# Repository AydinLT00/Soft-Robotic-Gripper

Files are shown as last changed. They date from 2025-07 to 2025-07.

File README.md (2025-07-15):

# Soft-Robotic-Gripper
# Bio-Inspired Soft Robotic Gripper with Arduino Control





This repository documents the design, fabrication, and testing of a 3-fingered, bio-inspired soft robotic gripper. The project leverages the intrinsic compliance of soft materials and an underactuated, tendon-driven mechanism to achieve adaptable and effective grasping of various objects. The entire system is controlled by a single servo motor managed by an Arduino Uno, demonstrating a low-cost, effective solution for robotic manipulation.

This work is inspired by the principles outlined in the paper *"A Bioinspired Soft Robotic Gripper for Adaptable and Effective Grasping"* (Manti et al., 2015).

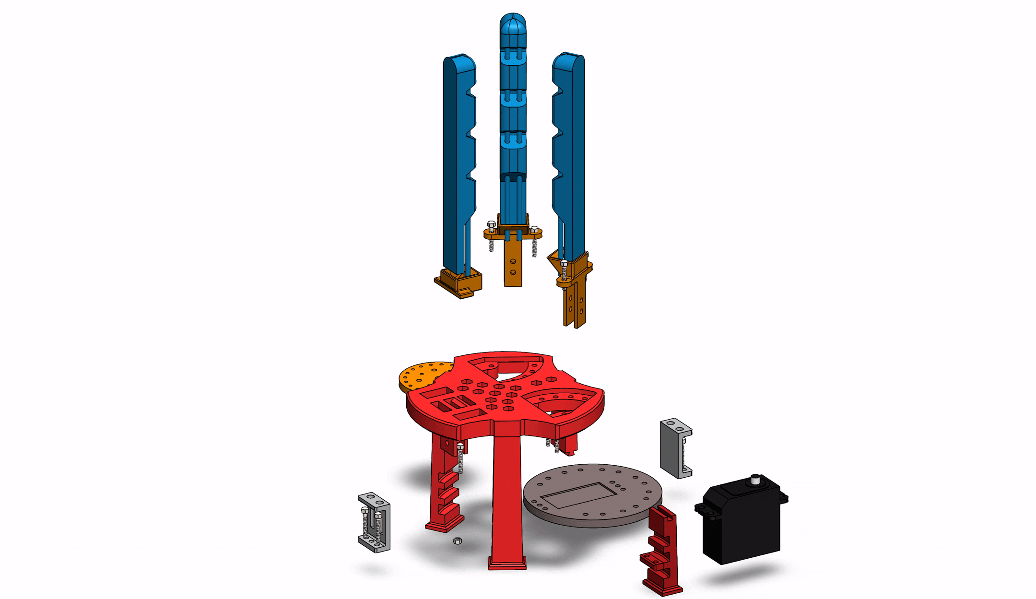
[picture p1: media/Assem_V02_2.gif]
CAD Render of the Gripper

*<p align="center">Final SolidWorks assembly of the soft gripper.</p>*

---

## 🚀 Showcase & Demos

The gripper successfully demonstrates versatile grasping capabilities, from delicate and irregular objects to lifting a significant payload.

### Live Grasping Demonstration
<!-- IMPORTANT: Create a GIF of your gripper in action and replace the URL below -->


*<p align="center">The gripper performing various pick-and-place tasks.</p>*

### Object Handling Capabilities
The gripper can handle a wide variety of shapes and sizes, thanks to its adaptive design.

| Gripping a Pack of Cookies | Holding a Screwdriver Set |
| :---: | :---: |
|  |  |

---

## 🔧 How It Works: Design & Principles

The gripper's effectiveness comes from a combination of four key design pillars.

### 1. Bio-Inspired Finger Design
The fingers are inspired by the biological structure of the human hand but are monolithically cast from soft silicone.
-   **Morphology:** Each finger has 4 phalanges created by 60° triangular cuts, promoting a larger contact area and natural bending.
-   **Materials:** We used a combination of silicones to balance flexibility and structural integrity:
    -   **Ecoflex™ 00-35:** A very soft silicone used for the ventral (gripping) side to maximize compliance and adapt to object shapes.
    -   **Smooth-Sil™ 950:** A stiffer silicone used for the dorsal side to provide restoring force and stability.
-   **Socket Integration:** The base of each finger is designed with a socket that interfaces with the 3D printed base, improving the flexion/extension mechanics.

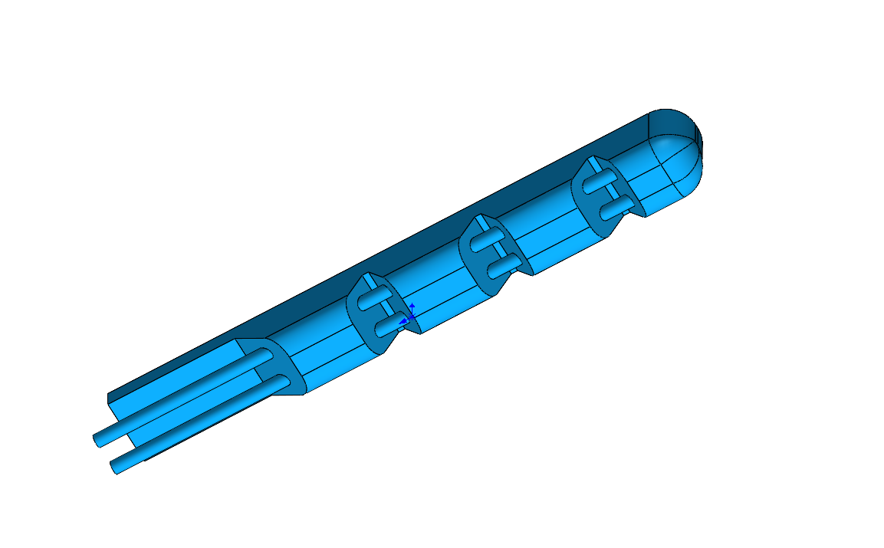
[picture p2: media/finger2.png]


### 2. Underactuated Tendon Mechanism
Simplicity and adaptability are achieved through an underactuated system.
-   **Single Actuator:** The entire 3-finger gripper is driven by a single high-torque servo motor.
-   **Differential Drive:** Multiple tendon (cable) is routed through all three fingers in a U-shape pattern. When the servo pulls the cable, it distributes the force among the fingers. If one finger is blocked, the others continue to close, allowing the gripper to passively conform to an object's shape.

### 3. 3D Printed Base
The palm of the gripper is a rigid base designed in SolidWorks and 3D printed.
-   **Function:** It serves as the mounting point for the fingers and integrates the servo motor.
-   **Features:** Includes tight-fit slots for the fingers to prevent wiggling and multiple mounting options for the servo plate.

| CAD Model | 3D Printed |
| :---: | :---: |
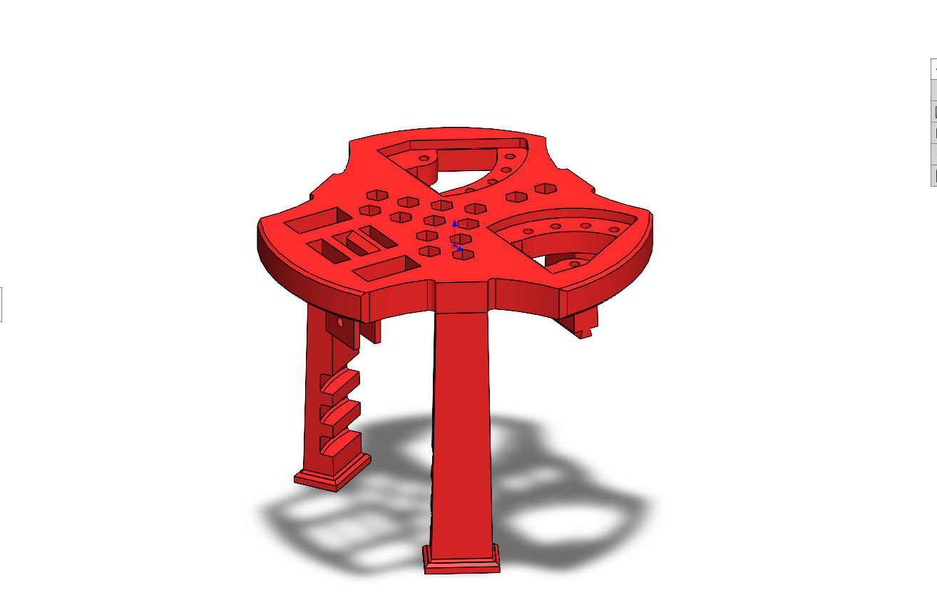
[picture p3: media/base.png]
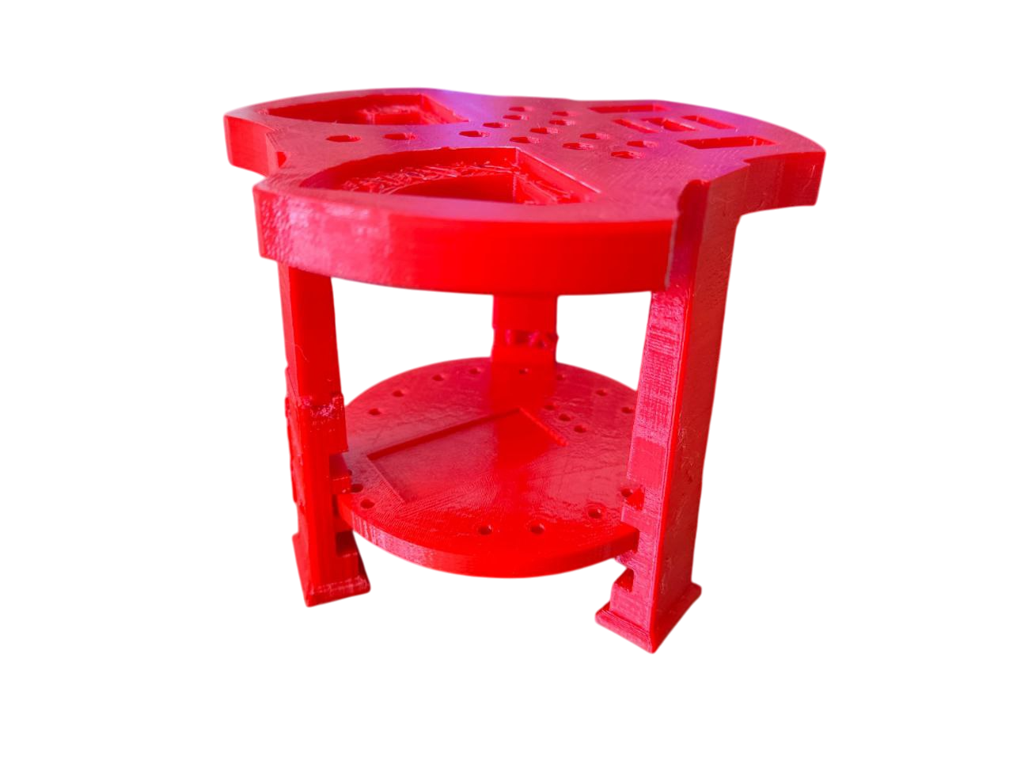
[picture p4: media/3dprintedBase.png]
|  |  |

### 4. Control System
The control is intentionally simple and low-cost.
-   **Hardware:** An **Arduino Uno** controls the position of the **servo motor**. The system is powered by a breadboard-based circuit.
-   **Software:** A simple script written in the **Arduino IDE** maps a desired grip state (open/closed) to a servo motor angle.

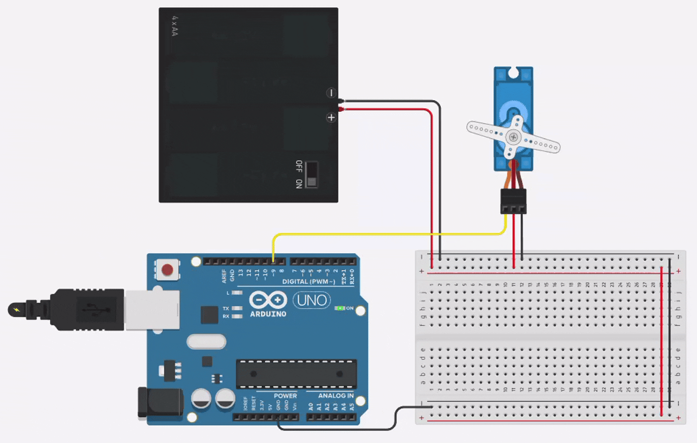
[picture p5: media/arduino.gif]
Control Circuit Diagram

*<p align="center">Circuit diagram for the servo motor control.</p>*

---

## 🛠️ Fabrication & Assembly

The fabrication process follows four main steps:
1.  **Design & Modeling:** The finger molds and base components were designed in **SolidWorks**.
2.  **3D Printing:** The molds and base were 3D printed using FDM technology with a 15% infill.
3.  **Casting:** The fingers were cast using the two-part silicone materials. Tubes were temporarily inserted into the molds to create pathways for the tendon cable.
4.  **Assembly & Wiring:** The cast fingers were mounted to the base, the servo was installed, and the tendon cable was routed and secured. Finally, the electronics were wired according to the circuit diagram.

---

## 📈 Performance & Results

-   **Payload Capacity:** The gripper successfully lifted a vertical payload of up to **1 Kg**.
-   **Grasping Versatility:** Demonstrated ability to handle delicate objects (like fruit) without damage and conform to irregular shapes.
-   **Limitations:** The gripper shows reduced stability on very smooth or wet surfaces (e.g., glass cups), where slipping can occur.

| PROS | CONS |
| :--- | :--- |
| ✅ **Adaptive Morphology:** Increased contact area and ability to handle delicate items. | ❌ **Limited Grip on Smooth Surfaces:** Prone to slipping on glass or wet objects. |
| ✅ **High Payload-to-Weight Ratio:** Lifts up to 1 Kg while being lightweight. | ❌ **Cleaning Challenges:** The soft Ecoflex material can be difficult to clean. |
| ✅ **Adjustable Configuration:** Finger orientation and tip distance can be manually set. | ❌ **Manual Configuration:** Setup requires manual adjustment. |
| ✅ **Fast & Low-Cost Fabrication:** Minimal printing hours and inexpensive materials. | ❌ **Friction in Cables:** Requires low-friction pathways for smooth actuation. |

---

## 💡 Future Work & Improvements

Based on the project's outcomes, several improvements could be implemented:
-   **Tension Adjustment Mechanism:** A mechanism to finely tune the tension of the tendon cables for each finger.
-   **High-Friction Cables/Pads:** Incorporating materials with a higher coefficient of friction to improve grip on smooth surfaces.
-   **Locking Mechanism:** A mechanical lock to hold the gripper in a specific configuration or grasp state without continuous servo power.

---

## ⚙️ How to Build Your Own

### Hardware Components
-   Arduino Uno
-   High-Torque Servo Motor (e.g., JX PDI-6221MG)
-   Ecoflex™ 00-35 & Smooth-Sil™ 950 Silicone
-   3D Printer and Filament (e.g., PLA)
-   Tendon Cable (e.g., high-strength fishing line)
-   Breadboard, Jumper Wires, and a 6V Power Supply

### Software & Files
-   **SolidWorks:** For viewing/editing the CAD files.
-   **Arduino IDE:** For programming the microcontroller.
-   **CAD Files:** All `.SLDPRT` and `.SLDASM` files are located in the `/SolidWorks` directory. Exported `.STL` files for printing are in the `/STL_for_Printing` directory.
-   **Arduino Code:** The control code is available in `/Arduino_Code/gripper_control.ino`.

### Assembly Instructions
1.  **3D Print** all components from the `/STL_for_Printing` directory.
2.  **Cast** the three soft fingers using the printed molds, following the two-part silicone mixing instructions.
3.  **Assemble** the base and mount the servo motor.
4.  **Mount** the fingers onto the base.
5.  **Route** the tendon cable through the fingers and attach it to the servo horn.
6.  **Wire** the electronics according to the circuit diagram above.
7.  **Upload** the `gripper_control.ino` sketch to your Arduino Uno.

---

## License

This project is shared for educational purposes. All rights are reserved. Please see the `LICENSE` file for more details.

## 🙏 Acknowledgments

This project was inspired by the work of Manti, Hassan, Passetti et al. and was completed as part of our studies at **Politecnico di Milano**. Special thanks to our professors and team members.

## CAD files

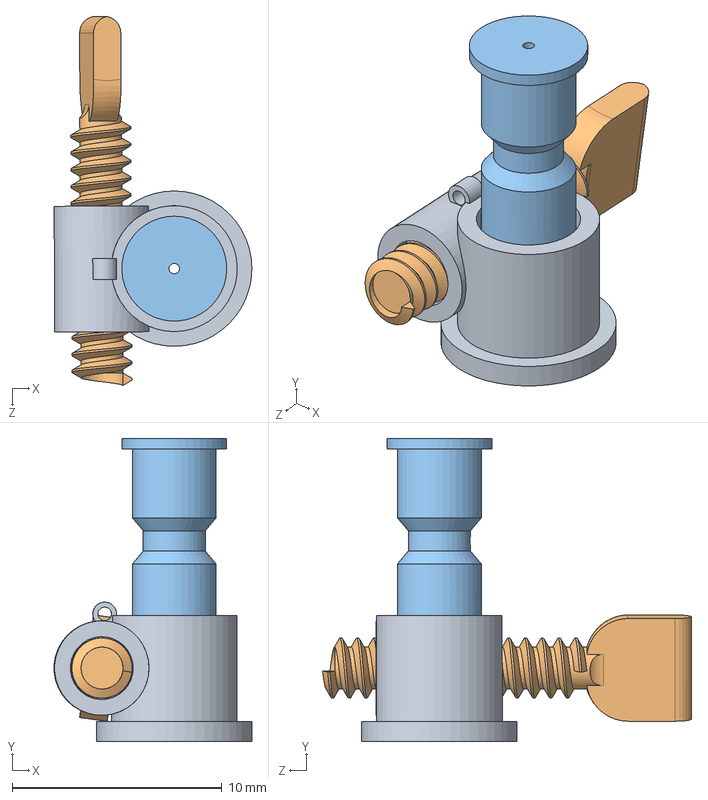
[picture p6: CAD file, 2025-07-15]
Solidworks/WormGearAssembly.SLDASM
9.43 x 14.4 x 17.6 mm
WormGearVertical
WormGearHorizontal
wormConnect

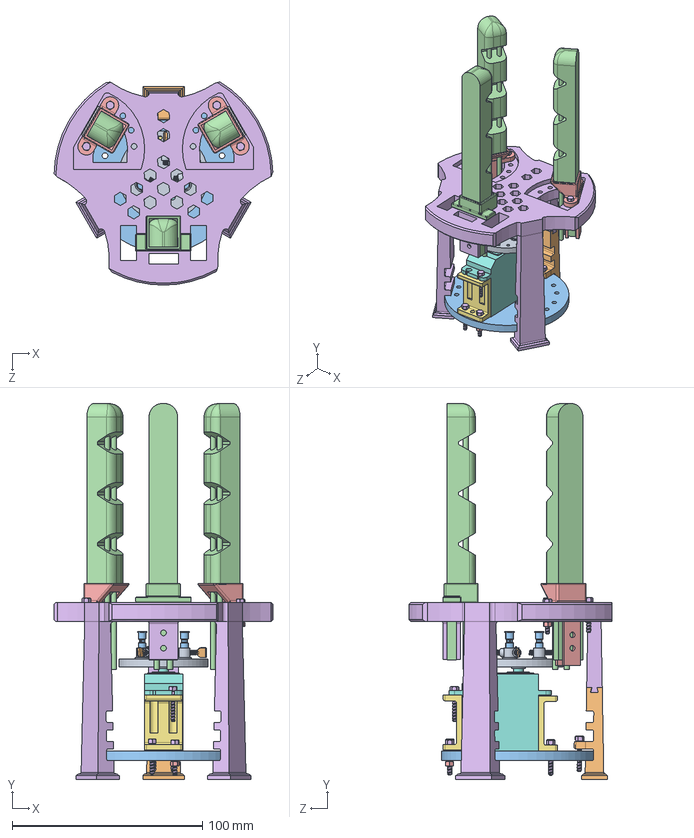
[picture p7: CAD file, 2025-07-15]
Solidworks/Assem_V02_WormGearCheck.SLDASM
115.0 x 197.5 x 106.8 mm
Base_main_attach_V02_WormGearCheck
rotate_binder_WormGearCheck x 2
FourPhalnges_V03_WormGearCheck x 3
ServoBase_V02_WormGearCheck
Base_main_body_v02_WormGearCheck
WireServoAttach_WormGearCheck
GXServo_WormGearCheck
attachServo_WormGearCheck x 2
nut_WormGearCheck x 11
bolt_WormGearCheck x 2
rotate_binder - Copy_noedge_WormGearCheck
WormGearVertical x 3
WormGearHorizontal x 3
wormConnect x 3

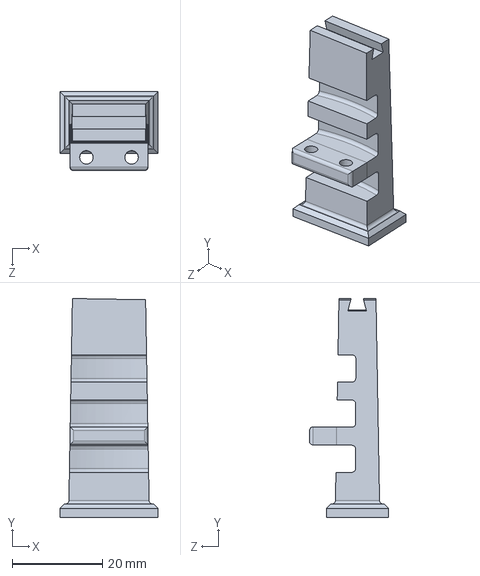
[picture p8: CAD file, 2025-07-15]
Solidworks/Base_main_body_v02_WormGearCheck.SLDPRT
21.8 x 48.5 x 17.6 mm

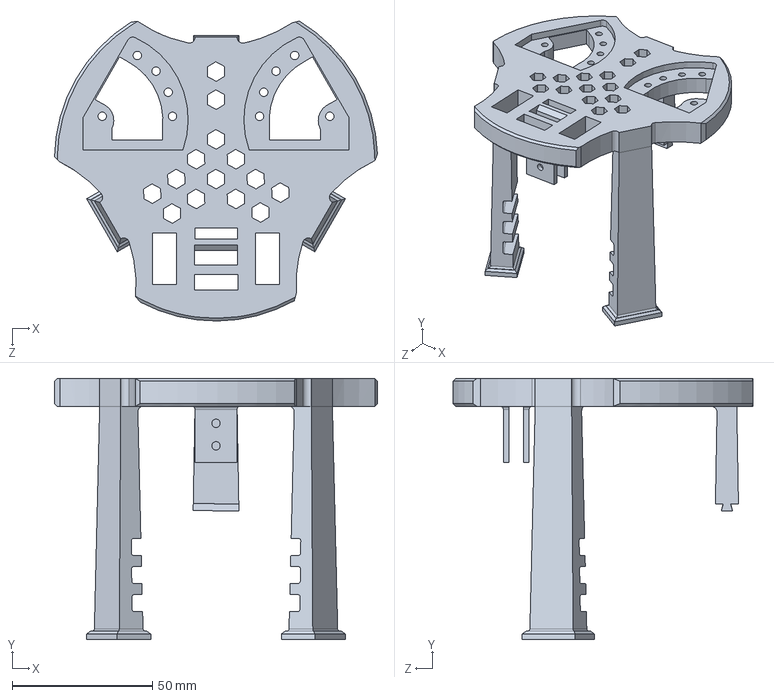
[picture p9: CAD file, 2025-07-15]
Solidworks/Base_main_attach_V02_WormGearCheck.SLDPRT
115.0 x 93.0 x 106.8 mm

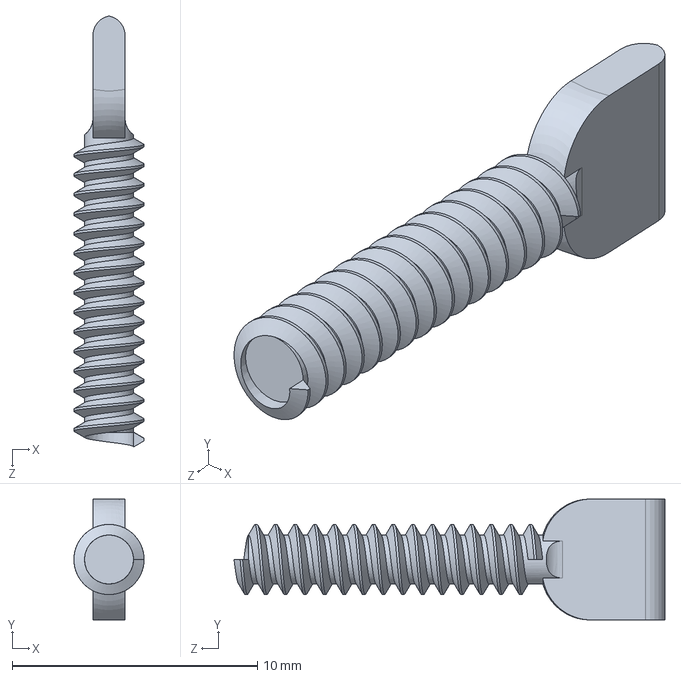
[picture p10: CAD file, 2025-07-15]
Solidworks/WormGearHorizontal.SLDPRT
2.87 x 4.94 x 17.6 mm

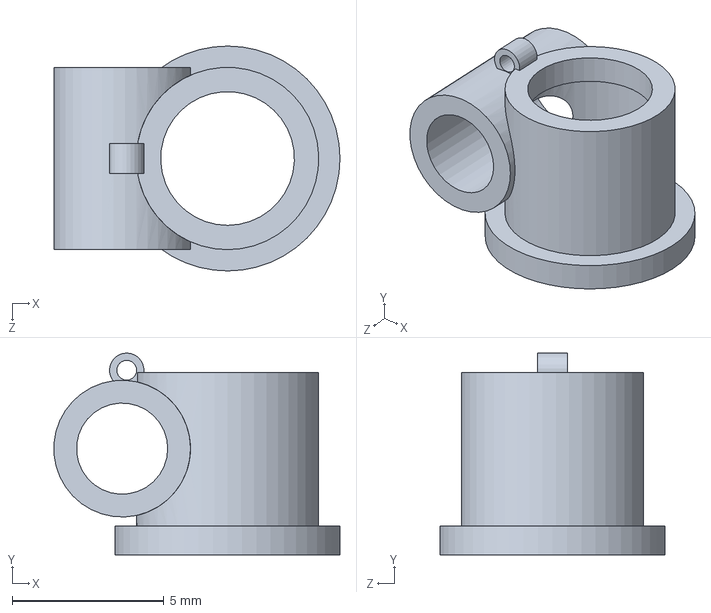
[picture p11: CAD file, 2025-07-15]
Solidworks/wormConnect.SLDPRT
9.41 x 6.65 x 7.40 mm

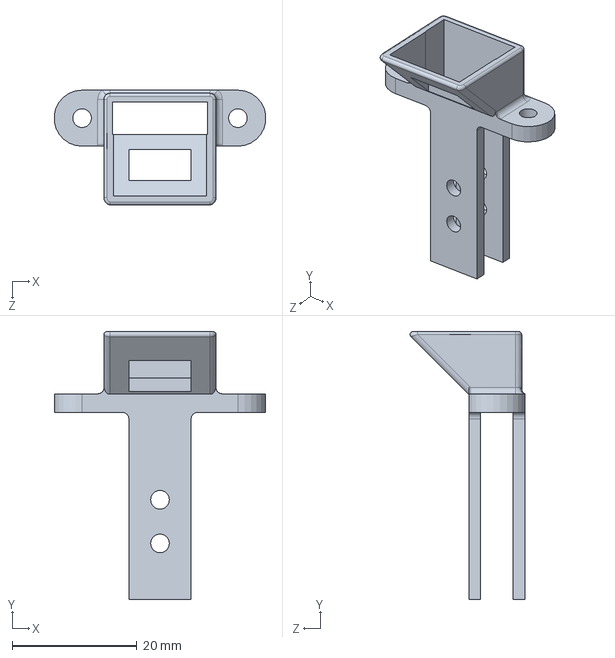
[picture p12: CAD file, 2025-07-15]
Solidworks/rotate_binder_WormGearCheck.SLDPRT
33.9 x 43.0 x 18.4 mm

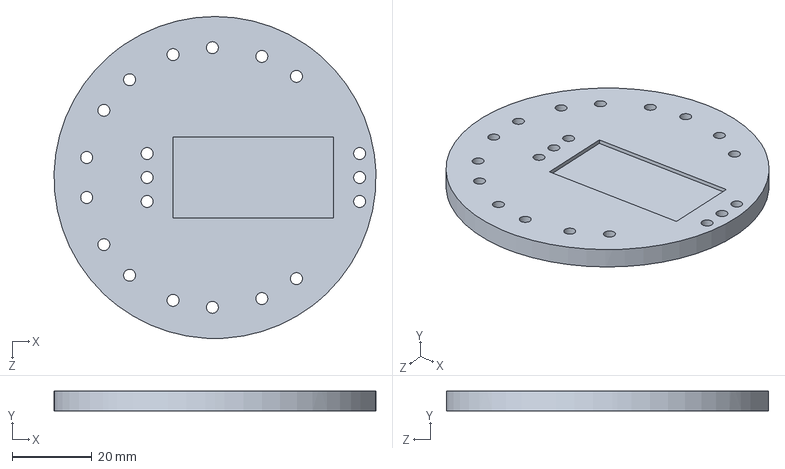
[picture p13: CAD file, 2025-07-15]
Solidworks/ServoBase_V02_WormGearCheck.SLDPRT
80.6 x 5.00 x 80.6 mm

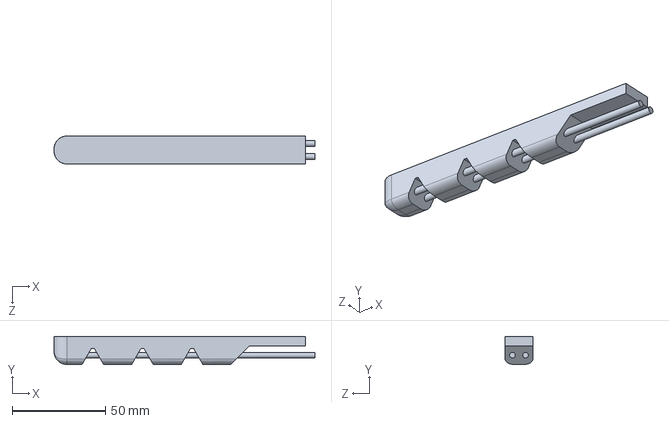
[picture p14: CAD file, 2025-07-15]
Solidworks/FourPhalnges_V03_WormGearCheck.SLDPRT
139.6 x 15.0 x 15.0 mm

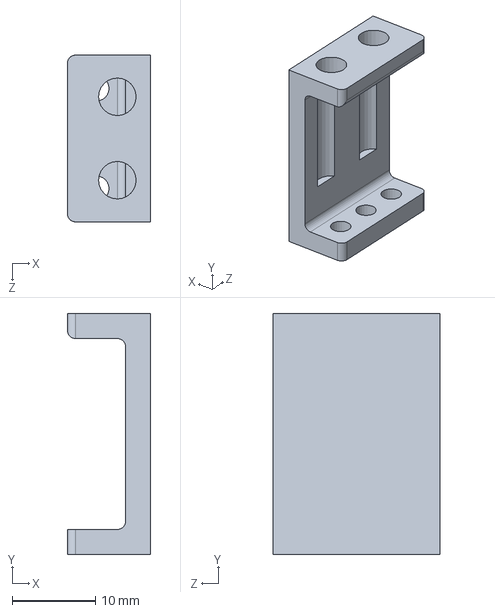
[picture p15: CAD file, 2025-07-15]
Solidworks/attachServo_WormGearCheck.SLDPRT
10.0 x 28.9 x 20.0 mm

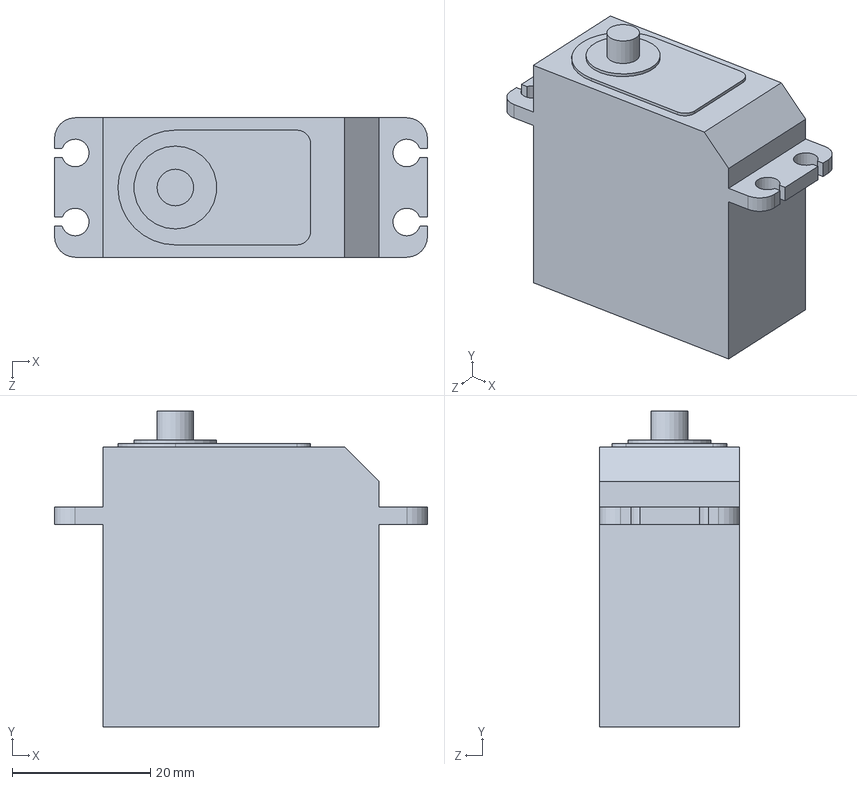
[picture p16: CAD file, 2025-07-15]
Solidworks/GXServo_WormGearCheck.SLDPRT
54.0 x 45.7 x 20.2 mm

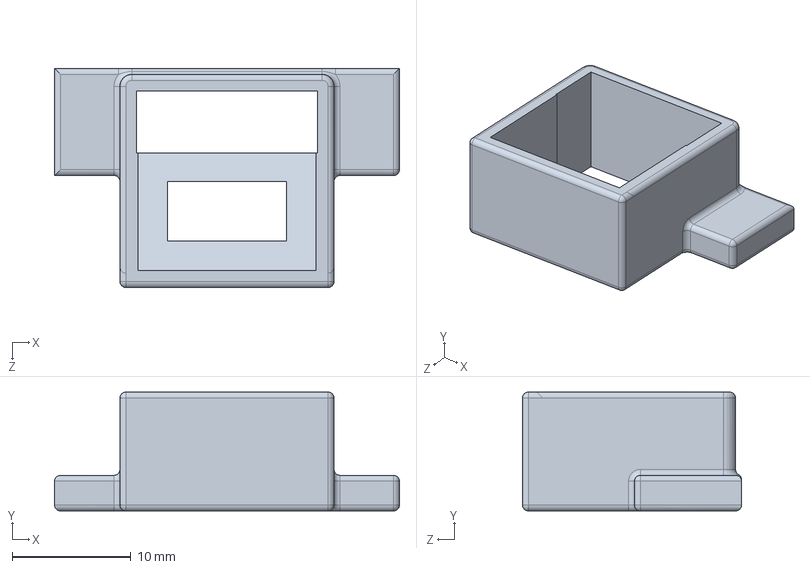
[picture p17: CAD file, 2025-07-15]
Solidworks/rotate_binder - Copy_noedge_WormGearCheck.SLDPRT
29.0 x 10.0 x 18.4 mm

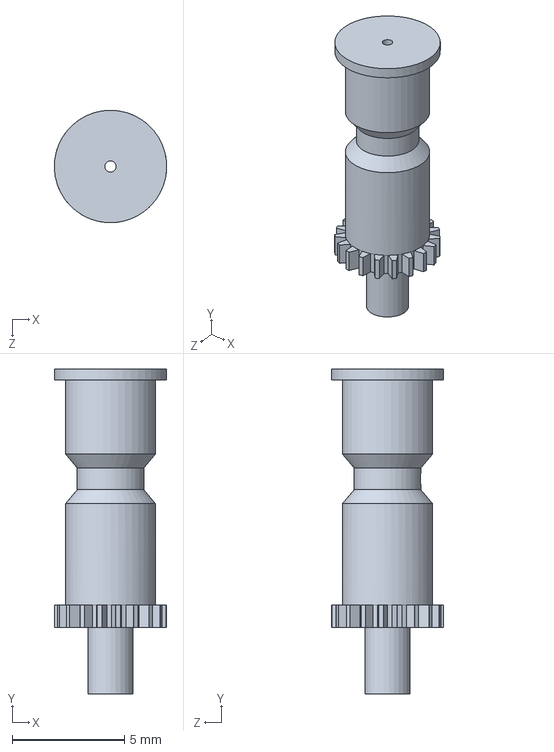
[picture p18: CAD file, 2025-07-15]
Solidworks/WormGearVertical.SLDPRT
5.00 x 14.4 x 5.00 mm

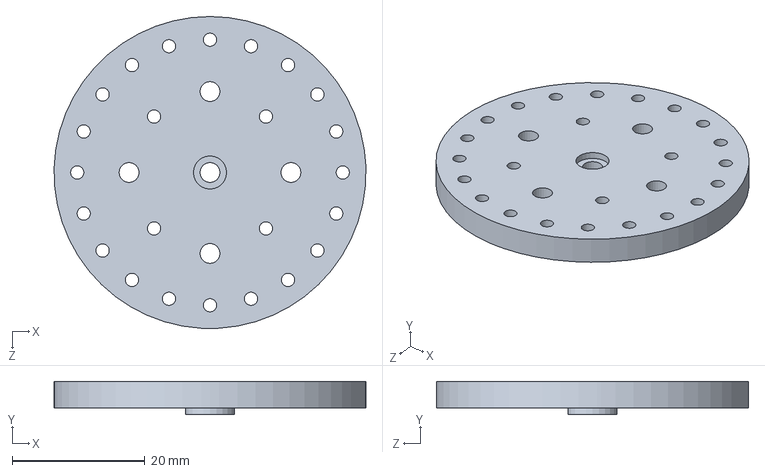
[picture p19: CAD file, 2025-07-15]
Solidworks/WireServoAttach_WormGearCheck.SLDPRT
47.0 x 5.00 x 47.0 mm

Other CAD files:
Solidworks/bolt_WormGearCheck.SLDPRT
Solidworks/nut_WormGearCheck.SLDPRT

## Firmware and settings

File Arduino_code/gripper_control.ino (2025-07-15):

/*
  Servo Control via Serial Monitor
  
  Description:
  This code allows you to control a servo motor connected to an Arduino Uno.
  - The servo is attached to pin 9.
  - By opening the Serial Monitor and typing "open", the servo rotates to 180 degrees.
  - By typing "close", the servo rotates to 0 degrees.

  Hardware:
  - Arduino Uno
  - Servo Motor
  - Jumper Wires

  Wiring:
  - Servo Signal Pin -> Arduino Pin 9
  - Servo VCC Pin    -> Arduino 5V
  - Servo GND Pin    -> Arduino GND
*/

// Include the standard Servo library
#include <Servo.h>

// Create a servo object to control the servo
Servo myServo;

// Define the pin the servo's signal wire is connected to
const int servoPin = 9;

// Define the angles for the "open" and "close" positions
// Standard servos have a range from 0 to 180 degrees.
const int openPosition = 180;
const int closePosition = 0;

void setup() {
  // Start the serial communication at a 9600 baud rate.
  // This is how the Arduino communicates with your computer.
  Serial.begin(9600);

  // Attach the servo object to the pin
  myServo.attach(servoPin);

  // Set the servo to the initial "close" position when the Arduino starts
  myServo.write(closePosition);
  
  // Print instructions to the Serial Monitor for the user
  Serial.println("Servo Control Initialized");
  Serial.println("-------------------------");
  Serial.println("Type 'open' to move to 180 degrees.");
  Serial.println("Type 'close' to move to 0 degrees.");
  Serial.println("-------------------------");
}

void loop() {
  // Check if there is any data available to read from the serial port
  if (Serial.available() > 0) {
    
    // Read the incoming command as a String until a newline character is received
    // (This happens when you press Enter in the Serial Monitor)
    String command = Serial.readStringUntil('\n');

    // Remove any leading/trailing whitespace from the command
    command.trim();

    // Use equalsIgnoreCase to make the command case-insensitive (e.g., "Open" or "OPEN" will also work)
    if (command.equalsIgnoreCase("open")) {
      Serial.println("Command received: open. Moving servo.");
      myServo.write(openPosition); // Tell the servo to go to the 'open' position (180 degrees)
    } 
    else if (command.equalsIgnoreCase("close")) {
      Serial.println("Command received: close. Moving servo.");
      myServo.write(closePosition); // Tell the servo to go to the 'close' position (0 degrees)
    } 
    else {
      // If the command is not recognized, print an error message
      Serial.print("Unknown command: '");
      Serial.print(command);
      Serial.println("'. Please use 'open' or 'close'.");
    }
  }
}

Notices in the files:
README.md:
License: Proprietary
